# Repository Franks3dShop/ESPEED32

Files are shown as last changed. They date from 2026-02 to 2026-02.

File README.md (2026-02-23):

# SlotEsp32
2026 Febuary 22 - minor version update to 2.07 (Franks3dShop)
Updates:
  - Change the Schematic HAL effect sensor for the correct TLE493D-P3B6A0
  - Change BOM to TLE493D-P3B6A0
  - Added support and tested support for TLE493D-W2B6, WARNING the resoluttion of this sensor is way less and trigger is less precise steping about 8% during acceleration.
  - Updated code to find version A0-A3 automatically
  - Added a space character for the car name
  - Inverted the rotation of the selector
  - Updated 3D parts source for Vertical Poles Magnets
  - Updated 3D parts source with parameter to offset vertically the Oled Window
  - Updated the .stl

WARNING: the magnetic sensor TLE493D-P3B6 A0 is the version 3 silicon available on Digikey or mouser. Please note the older version (P2) has issues , some other guys have been able to make it working, but I was not.  Please note, the last part (A0) of the part number is related to the address, if you purchase TLE493D-P3B6 A0 it will have 0x5D, A1 it will have 0x13, and so on, please double check the part number you ordered, and the datasheet for the proper address (I think we are using the 7 bit address )

Cutting edge Slot car controller that has an ESP32 at its heart.
How to built it video:
https://www.youtube.com/watch?v=JtMKeiguHKI
ThumbV2

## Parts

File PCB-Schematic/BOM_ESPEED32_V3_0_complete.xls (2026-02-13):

Comment | Designator | Footprint
Comment | Designator | Footprint | JLCPCB Part #（optional） | JLC BASIC/EXTENDED | Mounting Option | Quantity | Description
NO_POP_Mill-Max 2501-2-00-80-00-00-07-0 | 5V | TEST POINT MILL-MAX 2501-2-00-80-00-00-07-0 |  |  | DO NOT MOUNT | 1 | testpad 1mm diameter
BUZ9032SMD | BUZ | BUZ9032_SMD |  | BuySeparately |  | 1 | Header, 2-Pin
100nF | C1, C6, C8, C9, C10, C11, C12 | C0603 | C28233 | BASIC |  | 7 | CAP / CERA / 100nF / 25V / 10% / X8R (EIA) / -55°C to 150°C / 0603(1608) / SMD / -
10nF 50V 0603 | C2, C4, C7, C13, C14 | C0603 | C57112 | BASIC |  | 5 | CAPACITOR, European symbol
22uF | C3, C15, C16 | CAPC3225X270N | C13585 | BASIC |  | 3 | CAP / CERA / 22uF / 25V / 20% / X5R (EIA) / -55°C to 85°C / 1210(3225) / SMD / -
1uF | C5 | CAPC1608X87N-1 | C15849 | BASIC |  | 1 | CAP / CERA / 1uF / 25V / 20% / X5R (EIA) / -55°C to 85°C / 0603(1608) / SMD / -
5016 | CAP-, CAP+, GND, VIN+, WIPER | CON-SMD-TP-5016 |  |  | DO NOT MOUNT | 5 | Test Point, Compact, Surface Mount, Finish- Silver Plate
RF05VYM2SFH | D2 | DIO-SMD-RF05VYM2SFH | C509964 |  |  | 1 | Super Fast Recovery Diode
ZENER 10V(MM3Z10VT1G) | DZ3 | SOD323 | C39057 |  |  | 1 | Zener 10V MM3Z10VST1G
PEC11L-4120K-S0020 | ENC1 | SW-THT-PEC11L-4XXXK-SXXXX |  |  | DO NOT MOUNT | 1 | 11 mm Low Profile Encoder
HTSW-103-07-G-S | EXT_MOT, T_POT | CON-THT-2.54-3-1-8.38 |  |  |  | 2 | Through hole .025 SQ Post Header, 2.54mm pitch, 3 pin, vertical, single row
IFX7805ABTF | G1 | TO228P998X235-3N-2-V | C897464 | Extended |  | 1 | Three Terminal 1.0A Positive Voltage Regulator
OLED128x64 MDOB128064V2V-YI | OLED1 | OLED 128X64 1.3" |  |  |  | 1 | Header, 4-Pin
2N7002WT1G | Q1 | SOT65P220X100-3N | C232391 | Extended |  | 1 | Insulated-Gate Field-Effect Transistor (IGFET), N-Channel, Enhancement, Body Diode, Resistor Gate, ESD Diode Gate/Source, Pin 1 Gate, 2 Source, 3 Drain, 3 Pins
IPD90P03P4L-04 | Q2 | TO228P998X235-3N-2-V |  |  |  | 1 | OptiMOS - P2 Power-Transistor, P-channel-Enhancement mode, VDS -30V
0R | R1, R16, R18, R19 | R0603 | C21189 | DOUBLE CHECK |  | 4 | General Purpose Chip Resistor
10k | R2, R9, R10, R11, R12, R13, R15 | R0603 | C25804 | BASIC |  | 7 | RES / STD / 10k / 100mW / 5% / 100ppm/K / -55°C to 155°C / 0603(1608) / SMD / -
2.2k | R3, R6, R7, R8, R14, R20, R21, R22, R23, R24 | R0603 | C4190 | BASIC |  | 10 | RES / STD / 2.2k / 100mW / 1% / 100ppm/K / -55°C to 155°C / 0603(1608) / SMD / -
N.M. 0R | R4, R5 | R0603 |  |  |  | 2 | General Purpose Chip Resistor
PTS645SM43SMTR92 LFS | S1 | SW-SMD-PTS645SK43SMTR92 | C285473 |  |  | 1 | Tact Switches, Variety of Actuator Lengths
HTSW-104-07-G-S | SPARE | HDRV4W64P254_1X4_1016X248X838B |  |  | DO NOT MOUNT | 1 | Through hole .025 SQ Post Header, Hi-Temp Strip, 2.54mm pitch, 4 pin, vertical, single row
ESP32-DEVKIT-V1 | U1 | MODULE_ESP32_DEVKIT_V1 |  |  |  | 1 | Dual core, Wi-Fi: 2.4 GHz up to 150 Mbits/s,BLE (Bluetooth Low Energy) and legacy Bluetooth, 32 bits, Up to 240 MHz
BTN9960LV | U2 | IFX-PG-HSOF-7-1-V |  |  |  | 1 | MOTIX Single Half-Bridge with Integrated Driver IC
TLE493D-P3B6 A0 | U3 | SOP95P280X110-6N-V |  |  |  | 1 | Low Power 3D Hall Sensor with I2C Interface and Wake Up Function, Temp Range(-40 to 125°C)
LEGENDA:(colour code)
Not mounted but Nice to havefrom digik | Extended of Basic | NOT needed /not mounted |  |  |  | I will mount later by myself

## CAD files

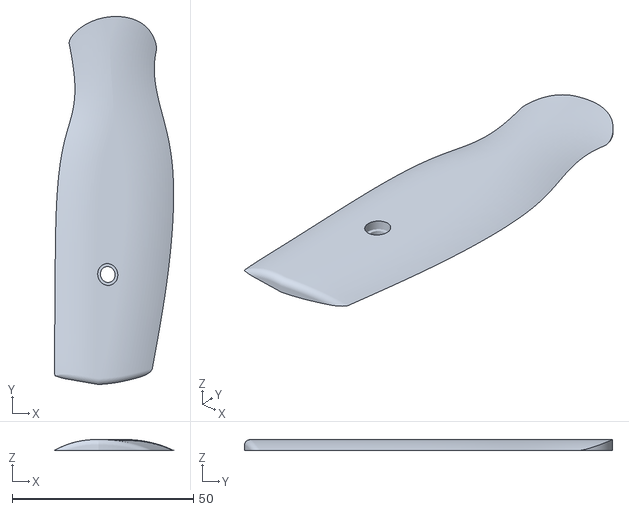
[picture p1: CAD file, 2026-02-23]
Mechanical/3DprintFiles/RoundingBot.stl
32.9 x 101.4 x 3.00

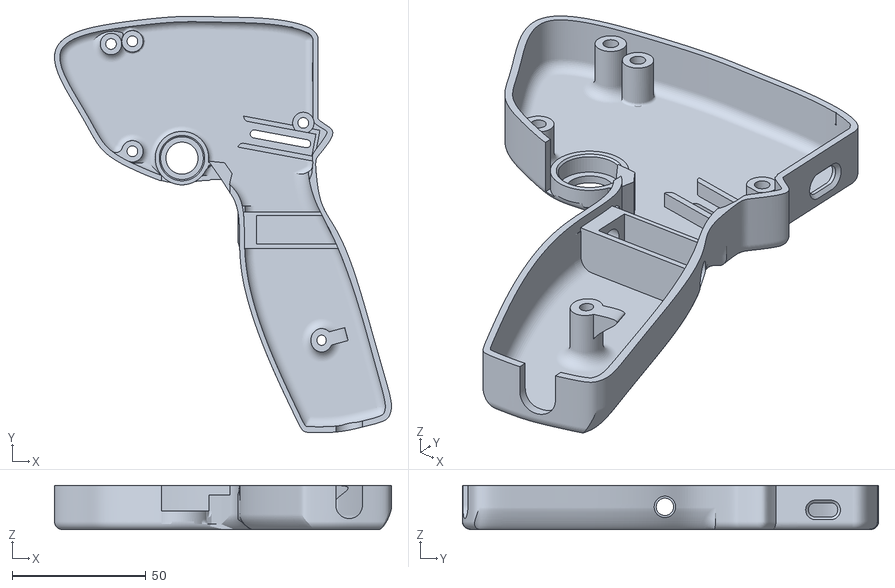
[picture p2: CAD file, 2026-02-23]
Mechanical/3DprintFiles/HandleBot.stl
126.1 x 155.8 x 16.5

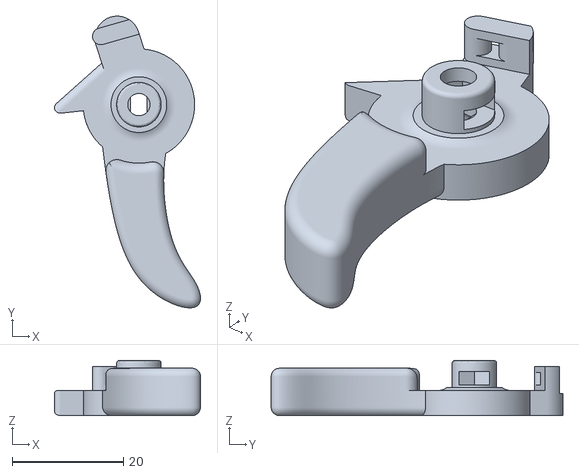
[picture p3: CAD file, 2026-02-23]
Mechanical/3DprintFiles/TrigV3.2 (Modified Vertical Magnets).stl
26.2 x 52.3 x 9.90

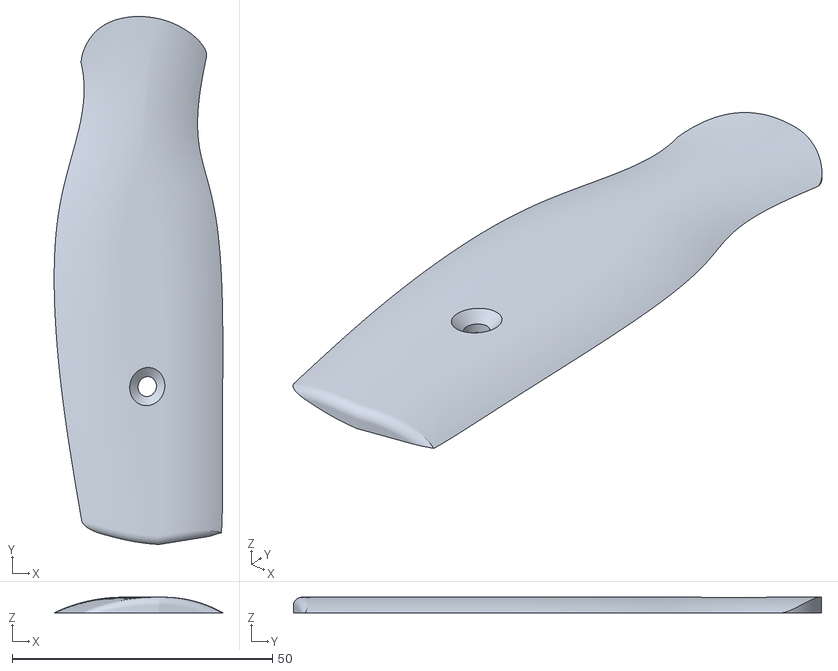
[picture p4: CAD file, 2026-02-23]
Mechanical/3DprintFiles/RoundingTop.stl
32.4 x 101.5 x 3.00

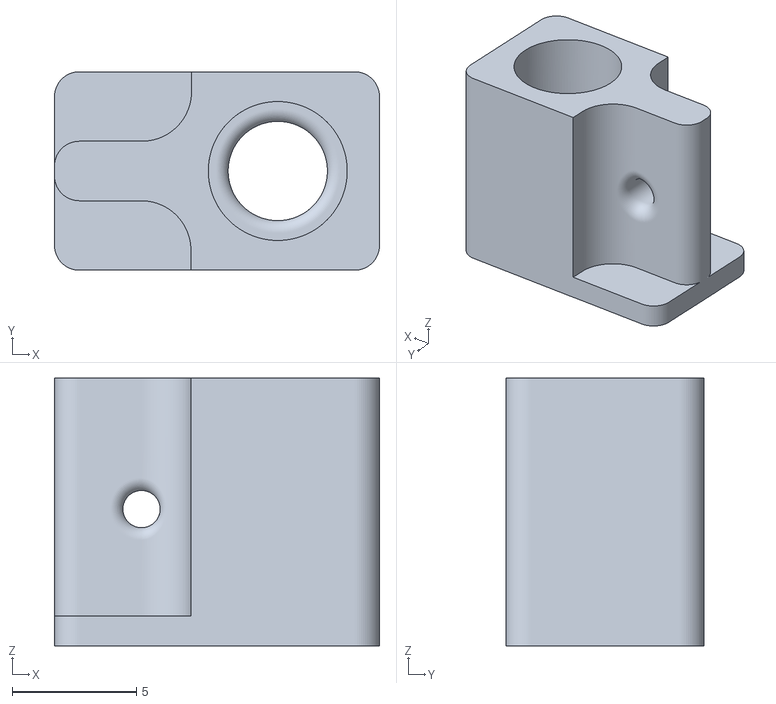
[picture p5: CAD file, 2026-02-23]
Mechanical/3DprintFiles/SpringMoveBlock.stl
13.1 x 8.00 x 10.8

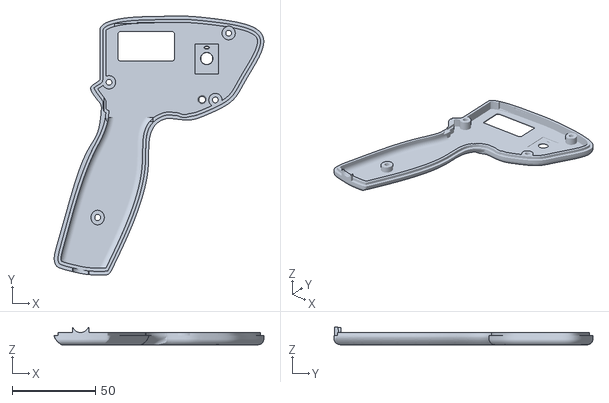
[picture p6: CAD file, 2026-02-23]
Mechanical/3DprintFiles/HandleTop (Moved).stl
126.1 x 155.8 x 10.6

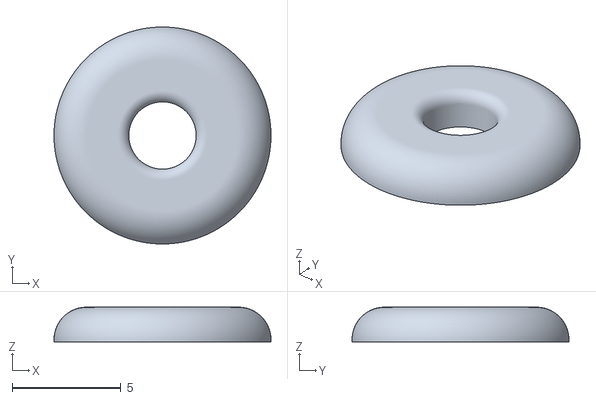
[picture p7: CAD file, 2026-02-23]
Mechanical/3DprintFiles/Trigger_Washer_Nut (Vertical Magnets).stl
10.0 x 10.00 x 1.60

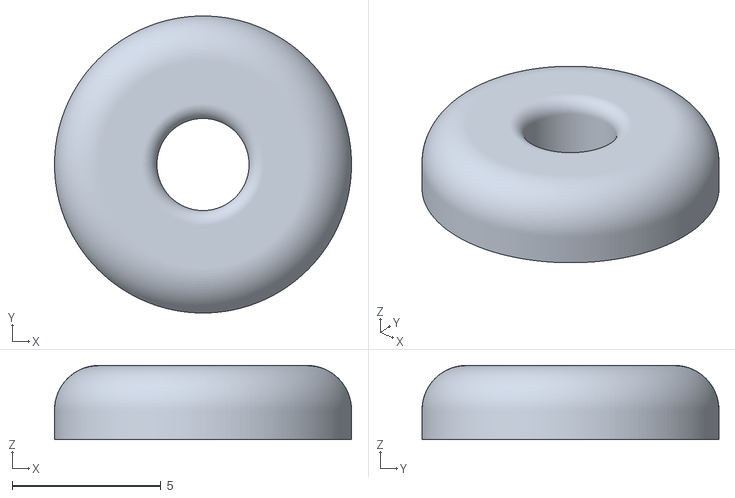
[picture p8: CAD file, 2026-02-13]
Mechanical/3DprintFiles/washerSlide.stl
10.0 x 10.00 x 2.50

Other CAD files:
Mechanical/3DprintFiles/TrigV3.2 (Orginal Radial Magnets).stl
Mechanical/3DprintFiles/HandleTop (Original).stl
Mechanical/3DprintFiles/Trigger_Washer_Nut (Radial Magnets).stl
Mechanical/ESPEED32_handle_v13.f3d

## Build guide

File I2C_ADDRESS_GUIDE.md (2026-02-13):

# 📍 I2C Address Guide - TLE493D-W2B6 and P3B6

## ⚠️ IMPORTANT: 7-bit vs 8-bit Addressing

Arduino and most I2C libraries use **7-bit addressing**, but some datasheets show **8-bit addresses**. This often creates confusion!

### Converting 7-bit ↔ 8-bit

```
8-bit WRITE address = (7-bit address × 2) + 0
8-bit READ address  = (7-bit address × 2) + 1

Example for W2B6-A1:
7-bit: 0x22
8-bit WRITE: 0x22 × 2 = 0x44
8-bit READ:  0x22 × 2 + 1 = 0x45
```

---

## 🔍 TLE493D-W2B6: The 4 Variants

The **TLE493D-W2B6** sensor comes in **4 versions** identified as A0, A1, A2, or A3. Each has a unique I2C address.

### Complete Address Table

| Variant | Chip Marking | 7-bit Address (Arduino) | 8-bit WRITE | 8-bit READ | Availability |
|---|---|---|---|---|---|
| **W2B6-A0** | TLE493D-W2B6-A0 | `0x1F` | `0x3E` | `0x3F` | ⭐⭐⭐ Most common |
| **W2B6-A1** | TLE493D-W2B6-A1 | `0x22` | `0x44` | `0x45` | ⭐⭐⭐ Common |
| **W2B6-A2** | TLE493D-W2B6-A2 | `0x6E` | `0xDC` | `0xDD` | ⭐ Less common |
| **W2B6-A3** | TLE493D-W2B6-A3 | `0x44` | `0x88` | `0x89` | ⭐ Less common |

---

## 🎯 How to Identify My Variant?

### Method 1: Check chip marking
The sensor usually has an inscription:
- `TLE493D-W2B6-A0` → Variant A0 (address 0x1F)
- `TLE493D-W2B6-A1` → Variant A1 (address 0x22)
- etc.

### Method 2: I2C Bus Scanner

Use this simple code to discover the address:

```cpp
#include <Wire.h>

void setup() {
  Serial.begin(115200);
  Wire.begin(21, 22);  // SDA, SCL for ESP32
  
  Serial.println("\n=== I2C Scanner ===");
  
  for(byte addr = 1; addr < 127; addr++) {
    Wire.beginTransmission(addr);
    byte error = Wire.endTransmission();
    
    if (error == 0) {
      Serial.print("Device found at 0x");
      if (addr < 16) Serial.print("0");
      Serial.print(addr, HEX);
      
      // Identify known TLE493D variants
      switch(addr) {
        case 0x1F:
          Serial.println(" → TLE493D-W2B6-A0");
          break;
        case 0x22:
          Serial.println(" → TLE493D-W2B6-A1 (8-bit: 0x44/0x45)");
          break;
        case 0x44:
          Serial.println(" → TLE493D-W2B6-A3");
          break;
        case 0x5D:
          Serial.println(" → TLE493D-P3B6-A0");
          break;
        case 0x6E:
          Serial.println(" → TLE493D-W2B6-A2");
          break;
        default:
          Serial.println(" → Unknown device");
          break;
      }
    }
  }
  
  Serial.println("===================");
}

void loop() {}
```

### Method 3: Use Modified ESPEED32 Code

The code auto-detects and displays which variant you have:

```
=== TLE493D Sensor Detection ===
Scanning for TLE493D-W2B6
  Scanning W2B6 addresses (A0/A1/A2/A3 variants)...
✓ Sensor found at address: 0x22 (W2B6-A1, 8-bit: 0x44/0x45)
✓ Sensor configured successfully
================================
```

---

## 🤔 Practical Cases - Resolving Confusion

### Case 1: "I have address 0x44 but don't know which variant"

**Two possibilities:**

#### If you see 0x44 in your **Arduino I2C scanner (7-bit)**:
→ You have a **TLE493D-W2B6-A3** (7-bit address = 0x44)

#### If you see 0x44 in a **datasheet as "write address"**:
→ You probably have a **TLE493D-W2B6-A1** (7-bit = 0x22, 8-bit write = 0x44)

**Simple solution:** Use the modified ESPEED32 code which auto-detects!

---

### Case 2: "My datasheet shows 0x3E but scanner finds 0x1F"

**This is normal!** 
- 0x3E = 8-bit WRITE address
- 0x1F = 7-bit address (Arduino)
- 0x3E ÷ 2 = 0x1F ✅

You have a **TLE493D-W2B6-A0**.

---

## 🔧 TLE493D-P3B6: The Variants

The **TLE493D-P3B6** (newer version) comes in 2 variants:

| Variant | 7-bit Address (Arduino) | 8-bit WRITE | 8-bit READ | Notes |
|---|---|---|---|---|
| **P3B6-A0** | `0x5D` | `0xBA` | `0xBB` | Standard version |
| **P3B6-A1** | `0x35` | `0x6A` | `0x6B` | Alternative address |

---

## 📐 I2C Connection Schematic

```
ESP32                    TLE493D-W2B6
                         
GPIO21 (SDA) ----+------ SDA (pin 5)
                 |
              [4.7kΩ]
                 |
                3.3V
                
GPIO22 (SCL) ----+------ SCL (pin 6)
                 |
              [4.7kΩ]
                 |
                3.3V
                
3.3V --------------------  VDD (pin 1)
                
GND ---------------------  GND (pin 2,3,4)

Note: Pins may vary depending on package (PG-SSO-3, PG-TSOP-6, etc.)
Check your specific datasheet.
```

---

## 🎓 Using Multiple Sensors

To use **multiple TLE493D** simultaneously:

1. Choose variants with different addresses
2. Example: A0 (0x1F) + A1 (0x22) + A3 (0x44)
3. Connect all on same I2C bus
4. Address each individually in code

**Example code:**

```cpp
#define SENSOR1_ADDR 0x1F  // W2B6-A0
#define SENSOR2_ADDR 0x22  // W2B6-A1
#define SENSOR3_ADDR 0x44  // W2B6-A3

// Read sensor 1
Wire.beginTransmission(SENSOR1_ADDR);
// ... reading ...

// Read sensor 2
Wire.beginTransmission(SENSOR2_ADDR);
// ... reading ...
```

---

## 💡 Summary - Key Points

1. **Arduino uses 7-bit addresses**
   - If scanner finds 0x22, that's the correct address for Arduino
   - No conversion needed

2. **W2B6 has 4 variants: A0, A1, A2, A3**
   - Each has different address
   - Most common are A0 (0x1F) and A1 (0x22)

3. **Modified ESPEED32 code auto-detects**
   - Scans all 4 possible addresses
   - Tells you which variant you have
   - No manual configuration needed

4. **Address 0x44 = two possibilities**
   - W2B6-A3 in 7-bit addressing
   - OR W2B6-A1 in 8-bit addressing (real address = 0x22)
   - Arduino I2C scanner gives the answer

---

**Created**: February 13, 2026  
**Updated**: Support for 4 W2B6 variants (A0/A1/A2/A3)  
**Author**: Claude (Anthropic)

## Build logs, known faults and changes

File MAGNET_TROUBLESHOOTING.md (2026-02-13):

# 🧲 Magnet Troubleshooting - No Reading Changes

## 🔍 Problem Diagnosis

Your TLE493D communicates correctly (detected on I2C) but values don't change when you approach the magnet? Here are possible causes and solutions.

---

## 🎯 Cause 1: Incorrect Magnet Orientation (MOST COMMON!)

### The Problem
The TLE493D measures magnetic fields in **3D** (X, Y, Z axes). Magnet orientation relative to the sensor is **CRITICAL**.

### How the Sensor Works

```
        Top view of TLE493D
        
    ┌─────────────────────────┐
    │                         │
    │         ┌───┐           │
    │         │ • │  ← Sensor │
    │         └───┘           │
    │           ↑ Z (perpendicular)
    │           │             │
    │      Y ←──┼──→ X        │
    │           │             │
    └─────────────────────────┘
    
    Z: Perpendicular to sensor (through chip)
    X: Parallel to long edge
    Y: Parallel to short edge
```

### ✅ Solution: Orient Magnet Correctly

**For slot car controller (angle measurement):**

The magnet must **ROTATE AROUND** the sensor, not just approach/move away!

```
Correct trigger configuration:

    Side view                  Top view
    
    ╔═══════╗                 ╔═══════╗
    ║       ║                 ║ [TLE] ║ ← Sensor
    ║ [TLE] ║ ← Sensor       ║       ║
    ║       ║                 ║   •   ║ ← Magnet position
    ╚═══════╝                 ╚═══════╝
        ↓                         ↓
        ↓                     Magnet rotates
    [  N  ]  ← Magnet        around sensor
    [  S  ]
    
    Magnet is parallel to PCB and ROTATES around the sensor!
```

**Simple test:**
1. Place magnet flat, parallel to sensor (about 5-10mm distance)
2. ROTATE the magnet around the sensor (360°)
3. Watch X and Y values in serial monitor
4. They should follow a sinusoidal cycle

---

## 🎯 Cause 2: Magnet Too Weak

### The Problem
TLE493D has measurement range of ±130 mT (milliTesla). If magnet is too weak, field won't be detected clearly.

### ✅ Solution: Use Appropriate Magnet

**Recommended magnets for slot car:**
- **Type**: Neodymium (NdFeB) - grade N35 or higher
- **Shape**: Disc or cylinder
- **Size**: 5-10mm diameter × 2-5mm thickness
- **Strength**: ~0.5-1 kg attraction force

**Magnets too weak (will NOT work well):**
- ❌ Fridge magnets (too weak)
- ❌ Standard ceramic magnets (too weak)
- ❌ Too small magnets (< 3mm)

### Magnet Strength Test
Your magnet should:
- ✅ Hold a light key suspended
- ✅ Stick firmly to a screwdriver
- ✅ Be felt through a 1.6mm PCB

---

## 🎯 Cause 3: Distance Too Large

### The Problem
Magnetic field decreases with square of distance. Too far = no signal.

### ✅ Solution: Optimal Distance

**For TLE493D-W2B6:**
- **Minimum distance**: 2-3mm (saturation risk if too close)
- **Optimal distance**: 5-10mm
- **Maximum distance**: 15-20mm (depends on magnet strength)

---

## 🎯 Cause 4: Sensor Reads But Code Doesn't Calculate Angle

### ✅ Solution: Check Raw Values

Add this debug code in `HAL.cpp`, function `HAL_ReadTriggerRaw()`:

```cpp
#elif defined (TLE493D_MAG)
  // ... existing code ...
  
  int16_t X = (int16_t)((buf[0] << 8) | ((buf[1] & 0x3F) << 2)) >> 2;
  int16_t Y = (int16_t)((buf[2] << 8) | ((buf[3] & 0x3F) << 2)) >> 2;
  
  // ⭐ ADD THESE LINES FOR DEBUG ⭐
  Serial.print("X: ");
  Serial.print(X);
  Serial.print(" | Y: ");
  Serial.print(Y);
  Serial.print(" | ");
  // ⭐ END DEBUG ⭐
#endif
```

**What you should see:**
- **X and Y change** when rotating magnet → Sensor works ✅
- **X and Y stay constant** (e.g., X=0, Y=0) → Reading problem ❌

---

## 🔬 Complete Test Program

Use this test code to diagnose the problem:

```cpp
// TLE493D Test - Put in loop()
void testTLE493D() {
  static unsigned long lastPrint = 0;
  
  if (millis() - lastPrint > 100) {  // Print every 100ms
    uint8_t buf[7];
    
    // Read sensor data
    Wire1.requestFrom(TLE493D_detected_address, 7);
    for (uint8_t i = 0; i < 7; i++) {
      if (Wire1.available()) {
        buf[i] = Wire1.read();
      }
    }
    
    // Extract X, Y, Z (12-bit signed)
    int16_t X = (int16_t)((buf[0] << 8) | ((buf[1] & 0x3F) << 2)) >> 2;
    int16_t Y = (int16_t)((buf[2] << 8) | ((buf[3] & 0x3F) << 2)) >> 2;
    int16_t Z = (int16_t)((buf[4] << 8) | ((buf[5] & 0x3F) << 2)) >> 2;
    
    // Calculate magnetic field magnitude
    float magnitude = sqrt(X*X + Y*Y + Z*Z);
    
    // Calculate angle
    float angleRad = atan2(Y, X);
    float angleDeg = angleRad * 180.0 / PI;
    if (angleDeg < 0) angleDeg += 360;
    
    // Display
    Serial.print("X:");
    Serial.print(X);
    Serial.print(" Y:");
    Serial.print(Y);
    Serial.print(" Z:");
    Serial.print(Z);
    Serial.print(" | Mag:");
    Serial.print(magnitude, 1);
    Serial.print(" | Angle:");
    Serial.print(angleDeg, 1);
    Serial.println("°");
    
    lastPrint = millis();
  }
}
```

**Result Interpretation:**

| Observation | Diagnosis | Solution |
|---|---|---|
| X, Y, Z = 0 or constant | Sensor not reading | Check I2C, power |
| Magnitude < 50 | Magnet too weak/far | Stronger magnet, move closer |
| Angle doesn't change | Wrong orientation | Rotate magnet |
| Magnitude > 2000 | Saturation | Move magnet farther |
| Erratic values | Interference | Isolate sensor |

---

## 📐 Optimal Mechanical Configuration

### For Slot Car Controller

```
Trigger side view:

         Finger
           ↓
    ╔═════════════╗
    ║   Trigger   ║
    ║             ║
    ║    [N S]    ║ ← Magnet mounted on trigger
    ╚══════╪══════╝
           │ Pivot
           ↓
    ┌──────────────┐
    │              │
    │    [TLE]     │ ← Sensor fixed on PCB
    │              │
    └──────────────┘
         PCB

Rest position: Magnet above sensor (N-S axis vertical)
Trigger pressed: Magnet rotates around sensor
```

### Recommended Mounting

1. **Sensor-magnet distance**: 5-10mm
2. **Magnet parallel to PCB**: Yes ✅
3. **N-S axis of magnet**: Perpendicular to movement
4. **Rotation radius**: As short as possible around sensor

---

## ✅ Verification Checklist

Check each point:

- [ ] Sensor detected on I2C (detection message OK)
- [ ] I2C pull-up resistors present (4.7kΩ)
- [ ] Magnet is neodymium N35 or higher
- [ ] Magnet at least 5mm diameter
- [ ] Sensor-magnet distance between 5-10mm
- [ ] Magnet parallel to PCB (flat)
- [ ] Magnet ROTATES around sensor (doesn't just approach)
- [ ] No motor/transformer nearby
- [ ] Debug code shows X, Y, Z changing
- [ ] Values don't saturate (< 2000)

---

## 🆘 If Nothing Works

Run the 3D magnetic field scan:

```cpp
void scanMagneticField() {
  Serial.println("\n=== 3D Magnetic Field Scan ===");
  
  for (int i = 0; i < 10; i++) {
    uint8_t buf[7];
    Wire1.requestFrom(TLE493D_detected_address, 7);
    for (uint8_t j = 0; j < 7; j++) {
      if (Wire1.available()) buf[j] = Wire1.read();
    }
    
    int16_t X = (int16_t)((buf[0] << 8) | ((buf[1] & 0x3F) << 2)) >> 2;
    int16_t Y = (int16_t)((buf[2] << 8) | ((buf[3] & 0x3F) << 2)) >> 2;
    int16_t Z = (int16_t)((buf[4] << 8) | ((buf[5] & 0x3F) << 2)) >> 2;
    
    Serial.print(i);
    Serial.print(": X=");
    Serial.print(X);
    Serial.print(" Y=");
    Serial.print(Y);
    Serial.print(" Z=");
    Serial.println(Z);
    
    delay(500);
  }
  
  Serial.println("Now rotate magnet slowly...");
  Serial.println("===================================\n");
}
```

**Expected results:**
- Without magnet: X, Y, Z close to 0 (±50)
- With static magnet: Constant non-zero values
- **Rotating magnet: X and Y oscillate in opposite phase** ← **THIS IS WHAT YOU SHOULD SEE**

---

**Created**: February 13, 2026  
**For**: ESPEED32 with TLE493D  
**Problem**: Magnet produces no significant reading change

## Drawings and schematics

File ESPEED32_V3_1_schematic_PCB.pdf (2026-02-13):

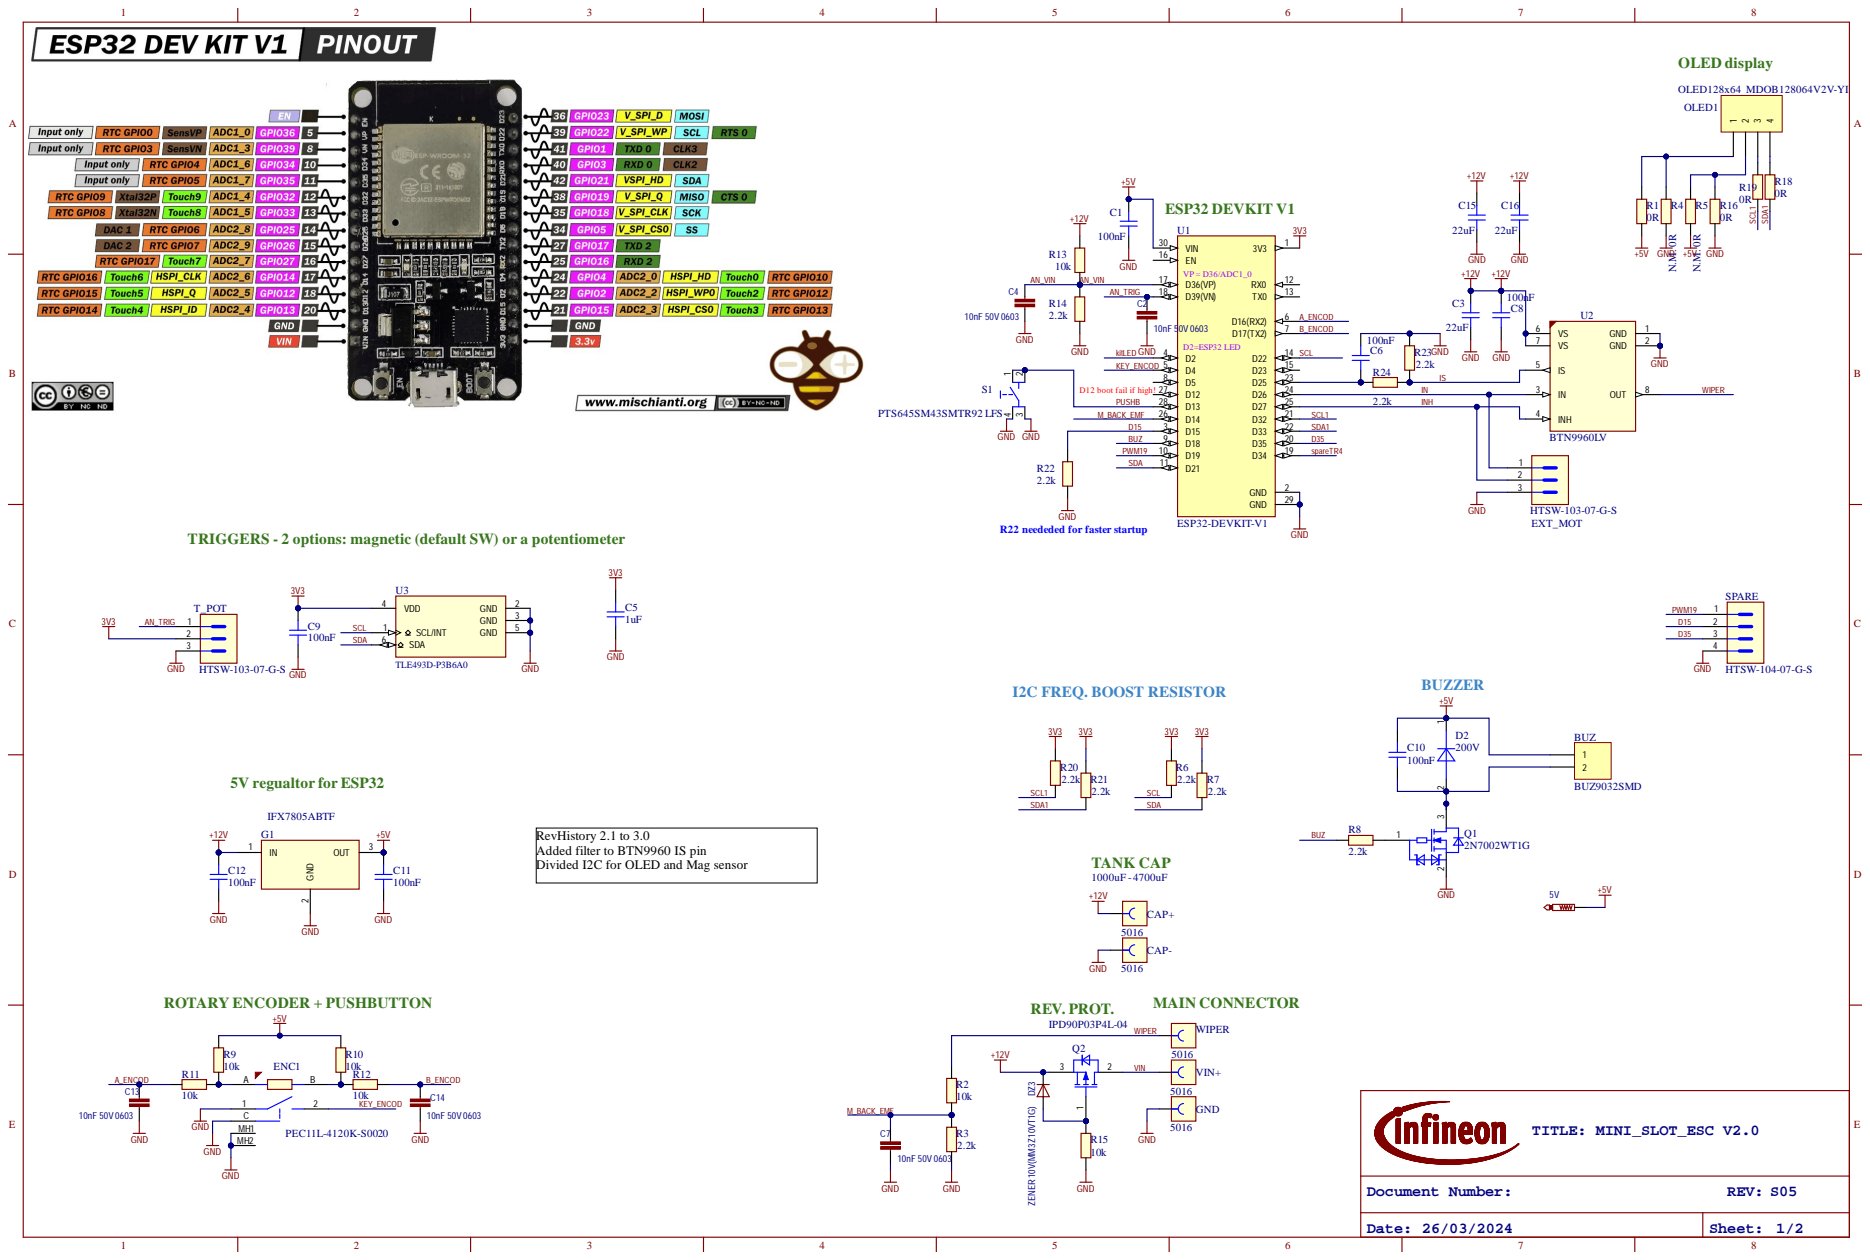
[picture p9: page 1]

Remarks: if not specified differently

D12 boot fail if high!

TRIGGERS - 2 options: magnetic (default SW) or a potentiometer

R22 neededed for faster startup

RevHistory 2.1 to 3.0
Added filter to BTN9960 IS pin
Divided I2C for OLED and Mag sensor

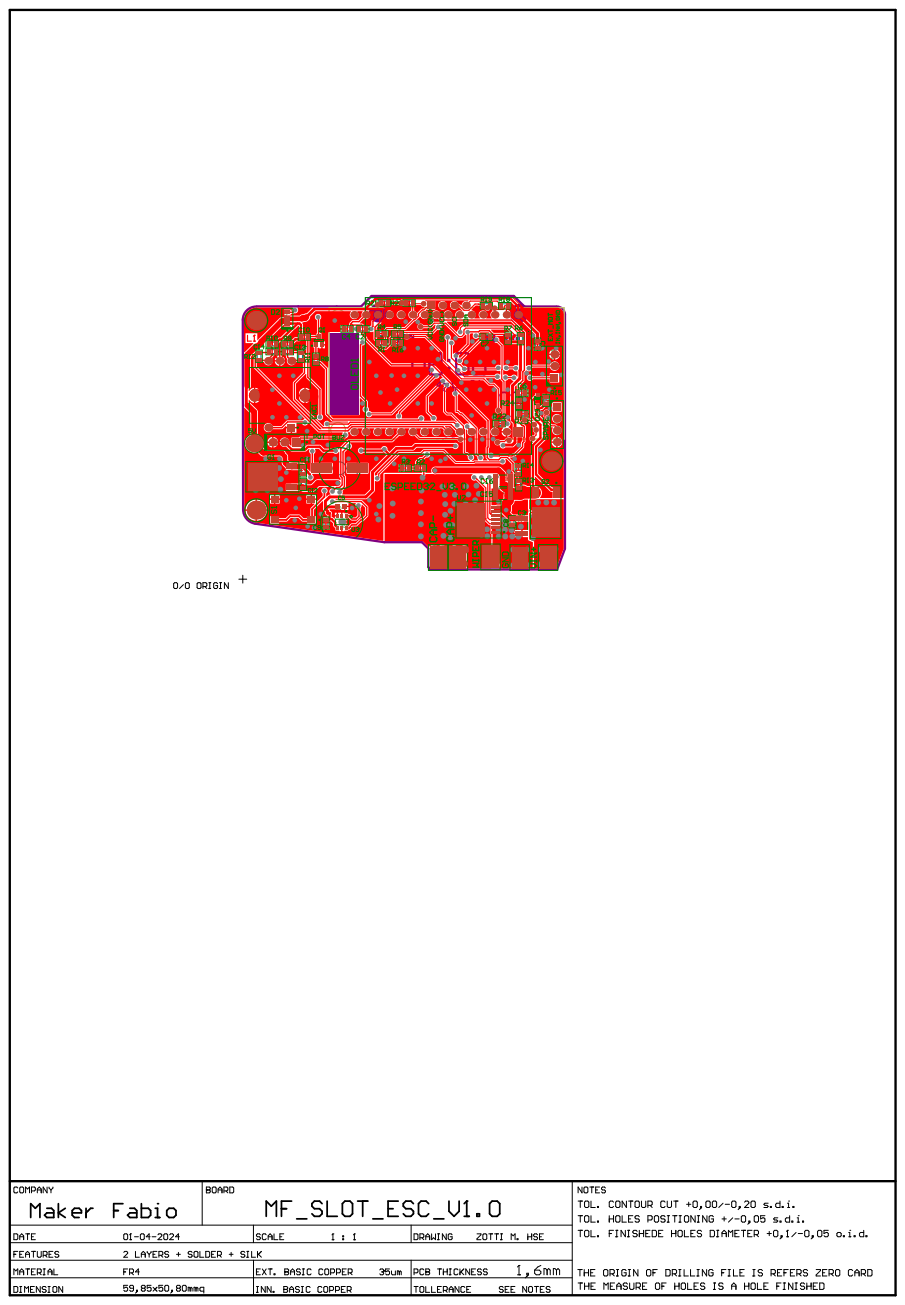
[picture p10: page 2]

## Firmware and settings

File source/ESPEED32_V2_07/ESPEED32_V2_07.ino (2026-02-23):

/*********************************************************************************************************************/
/*------------------------------------------------------Includes-----------------------------------------------------*/
/*********************************************************************************************************************/
#include "slot_ESC.h"

/*********************************************************************************************************************/
/*-------------------------------------------------------Macros------------------------------------------------------*/
/*********************************************************************************************************************/
#define BOOTLOADER_BUILD 1
//#define LOG_LOCAL_LEVEL ESP_LOG_NONE
#define CONFIG_BOOTLOADER_LOG_LEVEL ESP_LOG_NONE

#define SW_MAJOR_VERSION 2
#define SW_MINOR_VERSION 07
#define STORED_VAR_VERSION 4 /* tells which version of stored variable is used for thisproject in case the stored var */
                             /* changes from previous SW release, please increase the STORED_VAR_VERSION by 1         */

/* Last modified: 17/10/2024 */
/*********************************************************************************************************************/
/*-------------------------------------------------Global variables--------------------------------------------------*/
/*********************************************************************************************************************/

//CONFIG_BOOTLOADER_SKIP_VALIDATE_ON_POWER_ON=y not existing
//CONFIG_BOOTLOADER_SKIP_VALIDATE_IN_DEEP_SLEEP


TaskHandle_t Task1;
TaskHandle_t Task2;

static StateMachine_enum g_currState = INIT;
uint16_t debug;

/* Display Backbuffer */
#ifdef USE_BACKBUFFER
static uint8_t ucBackBuffer[1024];
#else
static uint8_t *ucBackBuffer = NULL;
#endif

OBDISP g_obd;       /* Display global instance */

char msgStr[50];    /* Display string global instance */


uint16_t g_carSel;  /* global variable telling whch car model has been selected */

/* Rotary Encoder global instance */
AiEsp32RotaryEncoder g_rotaryEncoder = AiEsp32RotaryEncoder(ENCODER_A_PIN, ENCODER_B_PIN, ENCODER_BUTTON_PIN, ENCODER_VCC_PIN, ENCODER_STEPS);

static uint8_t g_encoderMainSelector = 1;           /* Value of main menu selector (indicates selected item) */
static uint8_t g_encoderSecondarySelector = 0;      /* Value of secondarty selector (indicates selected item's value) */
static uint16_t *g_encoderSelectedValuePtr = NULL;  /* Global instance of pointer to the value selected by the encoder */


/* EEPROM stored values (mainly calibration) global instance */
StoredVar_type g_storedVar;

/* ESC internal variables gloabl instance */
ESC_type g_escVar{
  .outputSpeed_pct = 0,
  .trigger_raw = 0,
  .trigger_norm = 0,
  .encoderPos = 1,
  .Vin_mV = 0,
  .dualCurve = false
};

/* Main menu global instances */
Menu_type g_mainMenu{
  .lines = 3
};

/* Car menu global instances */
Menu_type g_carMenu{
  .lines = 3
};

/* Preferences global instance (for storing NVM data, replace EEPROM library) */
Preferences g_pref;

static uint32_t g_lastEncoderInteraction = 0;  /* tell how much time has passed since last time encoder whas rotated/pressed
                                                  so we can avoid keep printing the display menu and save CPU cycles */

/*********************************************************************************************************************/
/*--------------------------------------------- Function Declaration----------------------------------------*/
/*********************************************************************************************************************/
void IRAM_ATTR readEncoderISR();


/*********************************************************************************************************************/
/*---------------------------------------------Setup Function Implementations----------------------------------------*/
/*********************************************************************************************************************/

/* Setup */
void setup()
{
  /***** Pin and Serial Setup *****/
  HAL_PinSetup();

  /***** HalfBridge & HW Setup *****/
  HalfBridge_SetupFabio();

  /***** create a task that will be executed in the Task1code() and Task2code() funcitons, executed on core 0 and 1 *****/
  /* TASK1: slotESC state machine, managex OLED display and Encoder, low priority task */
  xTaskCreatePinnedToCore(
    Task1code, /* Task function. */
    "Task1",   /* name of task. */
    10000,     /* Stack size of task */
    NULL,      /* parameter of the task */
    1,         /* priority of the task */
    &Task1,    /* Task handle to keep track of created task */
    0);        /* pin task to core 0 */
  /* TASK2: perform trigger reading, trigger conditioning, PWM output */
  xTaskCreatePinnedToCore(
    Task2code, /* Task function. */
    "Task2",   /* name of task. */
    10000,     /* Stack size of task */
    NULL,      /* parameter of the task */
    2,         /* priority of the task */
    &Task2,    /* Task handle to keep track of created task */
    1);        /* pin task to core 1 */
}


/*********************************************************************************************************************/
/*---------------------------------------------MAIN LOOP IN TASKS----------------------------------------------*/
/*********************************************************************************************************************/

/**
 * Task 1: slotESC state machine: manage OLED display and Encoder, low priority task
 */
void Task1code(void *pvParameters) 
{
  for (;;) 
  {
    StateMachine_enum prevState = g_currState;  /* Keep track of the state at the previous loop */
    static uint16_t prevFreqPWM = 0;            /* Keep track if the PWM freq has changed */
    static MenuState_enum menuState = ITEM_SELECTION;   /* State of the Main Menu */
    static uint8_t swMajVer, swMinVer, storedVarVersion;/* SW major version, minor version,  storedVariable version stored in the eeprom */

    g_escVar.Vin_mV = HAL_ReadVoltageDivider(AN_VIN_DIV, RVIFBL, RVIFBH); /* Read VIN */

    if (g_currState != INIT) /* If the user params are already fetched from the EEPROM */
      {
        g_carSel = g_storedVar.selectedCarNumber;    /* Update global variable telling which car model is actually selected */
      }

    /* Task 1 state machine */
    switch (g_currState) {
      case INIT:

        g_pref.begin("stored_var", false); /* Open the "stored" namespace in read/write mode. If it doesn't exist, it creates it */
        
        if (g_pref.isKey("stored_var_ver") && g_pref.isKey("sw_maj_ver") && g_pref.isKey("sw_min_ver") && g_pref.isKey("user_param")) /* If all keys exists, then check their value */
        {
          /* Get the values of the sw version */
          swMajVer = g_pref.getUChar("sw_maj_ver");
          swMinVer = g_pref.getUChar("sw_min_ver");
          storedVarVersion = g_pref.getUChar("stored_var_ver");

          if ((storedVarVersion == STORED_VAR_VERSION) ) /* If the storedVariable version keys is equal to the STORED_VAR MACRO, then the stored param are already initialized woh the proper format*/
          {
            g_pref.getBytes("user_param", &g_storedVar, sizeof(g_storedVar)); /* Get the value of the stored user_param */
            initMenuItems();                                                  /* init menu items with EEPROM stored variables */

            /* If button is pressed at startup, go to CALIBRATION state */
            if (digitalRead(ENCODER_BUTTON_PIN) == BUTTON_PRESSED) 
            {
              g_currState = CALIBRATION;      /* Go to CALIBRATION state */
              /* Reset Min and Max to the opposite side, in order to have effective calibration */
              g_storedVar.minTrigger_raw = MAX_INT16;
              g_storedVar.maxTrigger_raw = MIN_INT16;
              calibSound();             /* Play calibration sound */
              initDisplayAndEncoder();  /* init and clear OLED and Encoder */

              /* Wait until button is released, then go to CALIBRATION state */
              while (digitalRead(ENCODER_BUTTON_PIN) == BUTTON_PRESSED)
              {
                showScreenPreCalibration();
              }
              
              obdFill(&g_obd, OBD_WHITE, 1); /* Clear OLED */
            }
            else  /* If button is NOT pressed at startup, go to RUNNING state */
            {
              g_currState = WELCOME;                    /* Go to WELCOME state */
              g_carSel = g_storedVar.selectedCarNumber; /* now it is safe to address the proper car */
              initDisplayAndEncoder();  /* init and clear OLED and Encoder */
              onSound();                /* Play ON sound */
            }

            g_pref.end(); /* Close the namespace */
            break;        /* Break the switch case: if code reaches here, it means that the stored user param and sw versions are OK */
          }
        }

        /* If the code reaches here it means that:
        - the sw version keys are not present --> stored var are not initialized
        - the sw version stored are not up to date --> stored var are initialized but might be outdated

        Calibration values are NOT stored, go to CALIBRATION state */
        initDisplayAndEncoder();  /* init and clear OLED and Encoder */
                              
        g_pref.clear();           /* Clear all the keys in this namespace */
        /* Store the correct SW version */
        g_pref.putUChar("sw_maj_ver", SW_MAJOR_VERSION);
        g_pref.putUChar("sw_min_ver", SW_MINOR_VERSION);
        
        g_pref.putUChar("stored_var_ver", STORED_VAR_VERSION);

        initStoredVariables();  /* Initialize stored variables with default values */

        /* Reset Min and Max to the opposite side, in order to have effective calibration */
        g_storedVar.minTrigger_raw = MAX_INT16;
        g_storedVar.maxTrigger_raw = MIN_INT16;
        calibSound();                   /* Play calibration sound */
        g_currState = CALIBRATION;      /* Go to CALIBRATION state */
        obdFill(&g_obd, OBD_WHITE, 1); /* Clear OLED */
        /* Press and release button to go to CALIBRATION state */
        while (!g_rotaryEncoder.isEncoderButtonClicked()) /* Loop until button is pressed */
        {
          showScreenNoEEPROM();
        }

        break;


      case CALIBRATION:
        /* Read Throttle */
        throttleCalibration(g_escVar.trigger_raw);    /* trigger raw is continuously read on task2 */
        showScreenCalibration(g_escVar.trigger_raw);  /* Show calibration screen */
        /* Exit calibration if button is presseded */
        if (g_rotaryEncoder.isEncoderButtonClicked())  /* exit calibration and save calibration data to EEPROM */
        {
          offSound();
          initMenuItems();  /* Init Menu Items */
          saveEEPROM(g_storedVar);  /* Save modified calibration values to EEPROM */
          HalfBridge_Enable();    /* Enable HalfBridge */
          g_currState = WELCOME;  /* Go to WELCOME state */
        }
        break;


      case WELCOME:
        /* This WELCOME state is only used to show the SW versions on the Screen, but the controller is actually fully operational:
            - Calibration is OKAY (either just done, or using stored values)
            - User param are OKAY (either just initialized to default, or using stored values)
            - Trigger is being read on Task 2

          The user trigger input is being elaborated and the correct speed (PWM) output is being produced for the whole duration of the WELCOME state */

        showScreenWelcome();    /* Show welcome screen */
        delay(1500);            /* Wait one second */
        g_currState = RUNNING;  /* Go to RUNNING state */
        break;


      case RUNNING: /* when the global variable State is in RUNNING the Task2 will elaborate the trigger to produce the PWM out */

        /* Change menu state if encoder button is clicked */
        if (g_rotaryEncoder.isEncoderButtonClicked()) 
        {
          menuState = rotary_onButtonClick(menuState);  /* This function is called if the encoder is pressed
                                                           Take the current menu state and returns the next menu state */
          g_lastEncoderInteraction = millis();          /* Update last encoder interaction */
        }

        /* Get encoder position if it was changed*/
        if (g_rotaryEncoder.encoderChanged()) 
        {
          g_escVar.encoderPos = g_rotaryEncoder.readEncoder();  /* Update the global ESC variable keeping track of the encoder value (position) */
          g_lastEncoderInteraction = millis();  /* Update last encoder interaction */
        }
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
void loop() {}

/*********************************************************************************************************************/
/*---------------------------------------------Setup Function Implementations----------------------------------------------*/
/*********************************************************************************************************************/

/*
  Initialize OLED display and encoder.
  This is done separately from the HW init to shorten the startup time.
*/
void initDisplayAndEncoder() 
{
  uint16_t rc;
  /***** OLED Display Setup *****/
  rc = obdI2CInit(&g_obd, MY_OLED, OLED_ADDR, FLIP180, INVERT_DISP, USE_HW_I2C, SDA1_PIN, SCL1_PIN, RESET_PIN, 800000L);  // use standard I2C bus at 400Khz
  if (rc != OLED_NOT_FOUND) 
  {
    obdSetBackBuffer(&g_obd, ucBackBuffer);
    obdFill(&g_obd, OBD_WHITE, 1);
  } 
  else 
  {
    Serial.println("Error! Failed OLED Display initialization!");
  }

  /***** Encoder Setup *****/
  g_rotaryEncoder.begin();
  g_rotaryEncoder.setup(readEncoderISR);
  g_rotaryEncoder.setBoundaries(1, MENU_ITEMS_COUNT, false); /* minValue, maxValue, circleValues true|false (when max go to min and vice versa) */
  g_rotaryEncoder.setAcceleration(MENU_ACCELERATION);        /* Larger number = more accelearation; 0 or 1 means disabled acceleration */
}


/* Rotary Encoder ISR */
void IRAM_ATTR readEncoderISR() {
  g_rotaryEncoder.readEncoder_ISR();
}


/**
 * Initialize the stored variables with default values.
   This is done for every CAR in the CarParam array.
 */
void initStoredVariables() {
  for (int i = 0; i < CAR_MAX_COUNT; i++) {
    g_storedVar.carParam[i].minSpeed = MIN_SPEED_DEFAULT;
    g_storedVar.carParam[i].brake = BRAKE_DEFAULT;
    g_storedVar.carParam[i].dragBrake = DRAG_BRAKE_DEFAULT;
    g_storedVar.carParam[i].maxSpeed = MAX_SPEED_DEFAULT;
    g_storedVar.carParam[i].throttleCurveVertex = { THROTTLE_CURVE_INPUT_THROTTLE_DEFAULT, THROTTLE_CURVE_SPEED_DIFF_DEFAULT };
    g_storedVar.carParam[i].antiSpin = ANTISPIN_DEFAULT;
    g_storedVar.carParam[i].freqPWM = PWM_FREQ_DEFAULT;
    g_storedVar.carParam[i].carNumber = i;
    sprintf(g_storedVar.carParam[i].carName, "CAR%1d", i);
  }
  g_storedVar.selectedCarNumber = 0;
  g_storedVar.minTrigger_raw = 0;
  g_storedVar.maxTrigger_raw = ACD_RESOLUTION_STEPS;
}


/**
 * Initialize the menu items with the value from the stored variables.
   Insert the items one by one in the main menu global instance.
   Then insert the items (cars) in the car menu.
   To add an item:
    - update the value of MENU_ITEMS_COUNT to match the amount of items in the menu.
    - update MAX_ITEMS so that it is greater or equal MENU_ITEMS_COUNT.
    - Add the item here, in the desired position (check the comment in slot_ESC.h MenuItem_type to know more).
 */
void initMenuItems() {
  int i = 0;
  /* Init menu items */

  sprintf(g_mainMenu.item[i].name, "BRAKE");
  g_mainMenu.item[i].value = (void *)&g_storedVar.carParam[g_carSel].brake;
  g_mainMenu.item[i].type = VALUE_TYPE_INTEGER;
  g_mainMenu.item[i].unit = '%';
  g_mainMenu.item[i].maxValue = BRAKE_MAX_VALUE;
  g_mainMenu.item[i].minValue = 0;
  g_mainMenu.item[i].callback = ITEM_NO_CALLBACK;

  sprintf(g_mainMenu.item[++i].name, "SENSI");
  g_mainMenu.item[i].value = (void *)&g_storedVar.carParam[g_carSel].minSpeed;
  g_mainMenu.item[i].type = VALUE_TYPE_INTEGER;
  g_mainMenu.item[i].unit = '%';
  g_mainMenu.item[i].maxValue = min(MIN_SPEED_MAX_VALUE, (int)g_storedVar.carParam[g_carSel].maxSpeed);
  g_mainMenu.item[i].minValue = 0;
  g_mainMenu.item[i].callback = ITEM_NO_CALLBACK;

  sprintf(g_mainMenu.item[++i].name, "ANTIS");
  g_mainMenu.item[i].value = (void *)&g_storedVar.carParam[g_carSel].antiSpin;
  g_mainMenu.item[i].type = VALUE_TYPE_INTEGER;
  g_mainMenu.item[i].unit = 'm';
  g_mainMenu.item[i].maxValue = ANTISPIN_MAX_VALUE;
  g_mainMenu.item[i].minValue = 0;
  g_mainMenu.item[i].callback = ITEM_NO_CALLBACK;

  sprintf(g_mainMenu.item[++i].name, "CURVE");
  g_mainMenu.item[i].value = (void *)&g_storedVar.carParam[g_carSel].throttleCurveVertex.curveSpeedDiff;
  g_mainMenu.item[i].type = VALUE_TYPE_INTEGER;
  g_mainMenu.item[i].unit = '%';
  g_mainMenu.item[i].maxValue = THROTTLE_CURVE_SPEED_DIFF_MAX_VALUE;
  g_mainMenu.item[i].minValue = THROTTLE_CURVE_SPEED_DIFF_MIN_VALUE;
  g_mainMenu.item[i].callback = &showCurveSelection;

  sprintf(g_mainMenu.item[++i].name, "PWM_F");
  g_mainMenu.item[i].value = (void *)&g_storedVar.carParam[g_carSel].freqPWM;
  g_mainMenu.item[i].type = VALUE_TYPE_DECIMAL;
  g_mainMenu.item[i].unit = 'k';
  g_mainMenu.item[i].maxValue = FREQ_MAX_VALUE / 100;
  g_mainMenu.item[i].minValue = FREQ_MIN_VALUE / 100;
  g_mainMenu.item[i].decimalPoint = 1;
  g_mainMenu.item[i].callback = ITEM_NO_CALLBACK;

  sprintf(g_mainMenu.item[++i].name, "LIMIT");
  g_mainMenu.item[i].value = (void *)&g_storedVar.carParam[g_carSel].maxSpeed;
  g_mainMenu.item[i].type = VALUE_TYPE_INTEGER;
  g_mainMenu.item[i].unit = '%';
  g_mainMenu.item[i].maxValue = MAX_SPEED_DEFAULT;
  g_mainMenu.item[i].minValue = max(5, (int)g_storedVar.carParam[g_carSel].minSpeed + 5);
  g_mainMenu.item[i].callback = ITEM_NO_CALLBACK;

  sprintf(g_mainMenu.item[++i].name, "*CAR*");
  g_mainMenu.item[i].value = (void *)&g_storedVar.carParam[g_carSel].carName;
  g_mainMenu.item[i].type = VALUE_TYPE_STRING;
  g_mainMenu.item[i].maxValue = CAR_MAX_COUNT - 1;  // so menu will scroll in the array (CAR_MAX_COUNT long)
  g_mainMenu.item[i].minValue = 0;
  g_mainMenu.item[i].callback = &showSelectRenameCar;

  /* Init Car selection menu items */
  for (uint8_t j = 0; j < CAR_MAX_COUNT; j++)
  {
    sprintf(g_carMenu.item[j].name, (const char *)g_storedVar.carParam[j].carName);
    g_carMenu.item[j].value = (void *)&g_storedVar.carParam[j].carNumber;
  }
}


/**
 * Show the Welcome screen
 */
void showScreenWelcome() 
{
  obdWriteString(&g_obd, 0, 16, 12, (char *)"ESPEED32", FONT_12x16, OBD_BLACK, 1);
  obdWriteString(&g_obd, 0, 16, 28, (char *)"BRM", FONT_12x16, OBD_BLACK, 1);
  sprintf(msgStr, "V%d.%02d", SW_MAJOR_VERSION, SW_MINOR_VERSION);  
  obdWriteString(&g_obd, 0, 16, 44, msgStr, FONT_12x16, OBD_WHITE, 1);
}


/**
 * Show the Pre-Calibration screen, when the button is pressed during startup, but not yet released
 */
void showScreenPreCalibration() 
{
  sprintf(msgStr, "ESPEED32 v%d.%02d", SW_MAJOR_VERSION, SW_MINOR_VERSION);  //print SW version
  obdWriteString(&g_obd, 0, 8, 0, msgStr, FONT_8x8, OBD_BLACK, 1);
  obdWriteString(&g_obd, 0, (OLED_WIDTH / 2) - 48, 1 * HEIGHT8x8, (char *)"Release button", FONT_8x8, OBD_BLACK, 1);
  obdWriteString(&g_obd, 0, (OLED_WIDTH / 2) - 48, 2 * HEIGHT8x8, (char *)"to calibrate", FONT_8x8, OBD_BLACK, 1);
  obdWriteString(&g_obd, 0, (OLED_WIDTH / 2) - 48, 3 * HEIGHT8x8, (char *)"     OR    ", FONT_8x8, OBD_BLACK, 1);
  obdWriteString(&g_obd, 0, (OLED_WIDTH / 2) - 48, 4 * HEIGHT8x8, (char *)"remove power", FONT_8x8, OBD_BLACK, 1);
  obdWriteString(&g_obd, 0, (OLED_WIDTH / 2) - 48, 5 * HEIGHT8x8, (char *)"  to exit  ", FONT_8x8, OBD_BLACK, 1);
}


/**
 * Show the screen indicating that the stored variables are not present in the EEPROM
 */
void showScreenNoEEPROM() 
{
  sprintf(msgStr, "ESPEED32 v%d.%02d", SW_MAJOR_VERSION, SW_MINOR_VERSION);  //print SW version
  obdWriteString(&g_obd, 0, 0, 0, msgStr, FONT_8x8, OBD_WHITE, 1);
  obdWriteString(&g_obd, 0, (OLED_WIDTH / 2) - 64, 3 * HEIGHT8x8, (char *)"EEPROM NOT init!", FONT_8x8, OBD_BLACK, 1);
  obdWriteString(&g_obd, 0, (OLED_WIDTH / 2) - 48, 5 * HEIGHT8x8, (char *)"Press button", FONT_8x8, OBD_BLACK, 1);
  obdWriteString(&g_obd, 0, (OLED_WIDTH / 2) - 48, 6 * HEIGHT8x8, (char *)"to calibrate", FONT_8x8, OBD_BLACK, 1);
}


/**
 * Show the calibration screen. It displays the current trigger raw value, as well as the max and min encountered values.
 * 
 * @param adcRaw The raw trigger value read from the ADC
 */
void showScreenCalibration(int16_t adcRaw)
{
  sprintf(msgStr, "CALIBRATION");
  obdWriteString(&g_obd, 0, (OLED_WIDTH - 66) / 2, 0, msgStr, FONT_6x8, OBD_WHITE, 1);

  sprintf(msgStr, "press/releas throttle");
  obdWriteString(&g_obd, 0, 0, 8, msgStr, FONT_6x8, OBD_BLACK, 1);

  sprintf(msgStr, "Raw throttle %4d  ", adcRaw);
  obdWriteString(&g_obd, 0, 0, 24, msgStr, FONT_6x8, OBD_BLACK, 1);

  sprintf(msgStr, "Min throttle %4d   ", g_storedVar.minTrigger_raw);
  obdWriteString(&g_obd, 0, 0, 32, msgStr, FONT_6x8, OBD_BLACK, 1);

  sprintf(msgStr, "Max throttle %4d   ", g_storedVar.maxTrigger_raw);
  obdWriteString(&g_obd, 0, 0, 40, msgStr, FONT_6x8, OBD_BLACK, 1);

  sprintf(msgStr, " push when done ");
  obdWriteString(&g_obd, 0, 0, 56, msgStr, FONT_6x8, OBD_BLACK, 1);
}
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

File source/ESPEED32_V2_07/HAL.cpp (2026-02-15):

/*********************************************************************************************************************/
/*------------------------------------------------------Includes-----------------------------------------------------*/
/*********************************************************************************************************************/
#include "HAL.h"
#include "slot_ESC.h"
#include <math.h>

#ifdef AS5600_MAG
  #include "AS5600.h"
  AS5600 as5600;   // define magnnetic sensor, use default Wire

#elif defined (AS5600L_MAG)
  #include "AS5600L.h"
  AS5600L as5600;// define magnnetic sensor,use default Wire the 5600L has differnt address

#elif defined (MT6701_MAG)
  #include "MT6701.hpp"
  MT6701 mt6701; // magnetic sensor, install MT6701 library by Noran Raskin

#elif defined (TLE493D_P3B6) || defined (TLE493D_W2B6)
  #include <Wire.h>                 // default I²C library
  
  /* TLE493D Sensor I2C Address Configuration */
  /* The TLE493D family has different variants with different I2C addresses */
  
  #if defined(TLE493D_W2B6)
    #include <Wire.h>                 // default I²C library
    // TLE493D-W2B6 I2C addresses (7-bit addressing)
    // The W2B6 comes in 4 variants: A0, A1, A2, A3 with different addresses
    // A0: 0x1F (default), A1: 0x22, A2: 0x6E, A3: 0x44
    // Note: 8-bit addresses shown in some datasheets are 7-bit << 1
    // Example: 0x44 (8-bit write) = 0x22 (7-bit) for version A1
    #define TLE493D_ADDRESS_A0  0x1F    // W2B6-A0 (most common)
    #define TLE493D_ADDRESS_A1  0x22    // W2B6-A1 (0x44 in 8-bit notation)
    #define TLE493D_ADDRESS_A2  0x6E    // W2B6-A2
    #define TLE493D_ADDRESS_A3  0x44    // W2B6-A3
    #define SENSOR_NAME "TLE493D-W2B6"
    
    // Array of all possible addresses to scan
    const uint8_t TLE493D_W2B6_addresses[] = {TLE493D_ADDRESS_A0, TLE493D_ADDRESS_A1, 
                                               TLE493D_ADDRESS_A2, TLE493D_ADDRESS_A3};
    
  #elif defined(TLE493D_P3B6)
    // TLE493D-P3B6 I2C addresses (7-bit addressing)
    // The P3B6 comes in 4 variants: A0, A1, A2, A3 with different addresses
    // Based on Infineon TLE493D family addressing scheme
    #define TLE493D_ADDRESS_A0  0x35    // P3B6-A0 (most common)
    #define TLE493D_ADDRESS_A1  0x22    // P3B6-A1 (shared with W2B6-A1)
    #define TLE493D_ADDRESS_A2  0x78    // P3B6-A2
    #define TLE493D_ADDRESS_A3  0x5D    // P3B6-A3
    #define SENSOR_NAME "TLE493D-P3B6"
    
    // Array of all possible addresses to scan
    const uint8_t TLE493D_P3B6_addresses[] = {TLE493D_ADDRESS_A0, TLE493D_ADDRESS_A1,
                                               TLE493D_ADDRESS_A2, TLE493D_ADDRESS_A3};
    
  #else
    // Default to W2B6 if neither is defined (as per schematic)
    #define TLE493D_PRIMARY_ADDRESS   0x1F
    #define TLE493D_SECONDARY_ADDRESS 0x5E
    #define SENSOR_NAME "TLE493D-W2B6 (default)"
    #warning "No TLE493D variant defined, defaulting to W2B6. Define TLE493D_W2B6 or TLE493D_P3B6 in HAL.h"
  #endif
  
  // Global variable to store the detected I2C address
  uint8_t TLE493D_detected_address = 0;

#endif

/*********************************************************************************************************************/
/*---------------------------------------------Function Implementations----------------------------------------------*/
/*********************************************************************************************************************/

void HAL_InitHW()
{
  /* Setup fo the parameters for serial(debug) communication */ 
  Serial.begin(115200);   // debug restore me
  delay(2000);            // ⭐ Attendre 2 secondes
  Serial.println("\n=== ESPEED32 STARTED ===\n");
  Serial.println("Debug Start");

  #if defined(TLE493D_W2B6)
    Wire1.begin(SDA0_PIN, SCL0_PIN, 400000L); // Initialize I2C for magnetic sensor
    
    // Auto-detect which TLE493D variant is connected
    bool sensor_found = false;
    
    Serial.println("=== TLE493D Sensor Detection ===");
    Serial.print("Scanning for ");
    Serial.println(SENSOR_NAME);
    
    // W2B6: Scan all 4 possible addresses (A0, A1, A2, A3 variants)
    Serial.println("  Scanning W2B6 addresses (A0/A1/A2/A3 variants)...");
    for (uint8_t i = 0; i < 4 && !sensor_found; i++) {
      uint8_t addr = TLE493D_W2B6_addresses[i];
      Wire1.beginTransmission(addr);
      if (Wire1.endTransmission() == 0) {
        TLE493D_detected_address = addr;
        sensor_found = true;
        Serial.print("✓ Sensor found at address: 0x");
        Serial.print(addr, HEX);
        Serial.print(" (");
        switch(addr) {
          case 0x1F: Serial.print("W2B6-A0"); break;
          case 0x22: Serial.print("W2B6-A1, 8-bit: 0x44/0x45"); break;
          case 0x6E: Serial.print("W2B6-A2"); break;
          case 0x44: Serial.print("W2B6-A3"); break;
          default: Serial.print("Unknown variant"); break;
        }
        Serial.println(")");
      }
    }
    
    if (!sensor_found) {
      Serial.println("✗ ERROR: TLE493D-W2B6 sensor not detected!");
      Serial.println("  Tried addresses: 0x1F (A0), 0x22 (A1), 0x6E (A2), 0x44 (A3)");
      Serial.println("  Note: 8-bit addresses are 2x 7-bit (e.g., 0x44 write = 0x22 in 7-bit)");
      Serial.println("  Please check:");
      Serial.println("  1. Sensor is properly connected");
      Serial.println("  2. I2C pullup resistors are present (4.7kΩ recommended)");
      Serial.println("  3. Correct sensor variant defined in HAL.h");
      Serial.println("  4. Check if you have W2B6-A0, A1, A2, or A3 variant");
      // Use A0 address as fallback
      TLE493D_detected_address = TLE493D_ADDRESS_A0;
    }
    
  #elif defined(TLE493D_P3B6)
    Wire1.begin(SDA0_PIN, SCL0_PIN, 1000000L); // Initialize I2C for magnetic sensor
    
    // Auto-detect which TLE493D variant is connected
    bool sensor_found = false;
    
    Serial.println("=== TLE493D Sensor Detection ===");
    Serial.print("Scanning for ");
    Serial.println(SENSOR_NAME);
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

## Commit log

2026-02-13 Add TLE493D-W2B6 sensor support
2026-02-15 Added TLE493D Adresse Detection, Fixed Rotary Encoder rotation, Added Space as a Character, Fixed W2B6
    [HAL.cpp, HAL.h]
2026-02-23 Updated .stl files and .f3d Fusion source.
    [ESPEED32_handle.f3d, ESPEED32_handle_v13.f3d, HandleBot.stl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]
